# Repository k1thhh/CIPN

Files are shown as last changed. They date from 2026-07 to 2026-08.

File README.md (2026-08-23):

# 🩺 Chemo Comfort — AI-Based Wearable for Early Detection of CIPN

<p align="center">

**Embedded Healthcare | TinyML | ESP32 | Biomedical Sensing | Edge AI**

</p>

<p align="center">
  
  
  
  
  
</p>

---

## 📌 Overview

**Chemo Comfort** is a portable, low-cost embedded diagnostic prototype designed for the **early, objective screening of Chemotherapy-Induced Peripheral Neuropathy (CIPN)**.

The system combines three complementary assessment methods:

* A simplified **EORTC QLQ-CIPN20 questionnaire**
* **Vibration Perception Threshold (VPT)** testing
* **Cold-temperature perception testing**

The extracted features are processed directly on an **ESP32-WROOM** using a quantized **TensorFlow Lite Micro neural network**, allowing the device to classify CIPN risk without relying on cloud connectivity.

The system produces one of three risk categories:

```text
Normal
Moderate
Severe
```

All processing is performed locally on the device, providing a privacy-preserving architecture suitable for potential home or outpatient applications.

> ⚠️ **Important:** Chemo Comfort is an academic/research prototype and is **not a certified medical device**. It is not intended for clinical diagnosis without further validation.

---

# 🩺 About Chemotherapy-Induced Peripheral Neuropathy

**Chemotherapy-Induced Peripheral Neuropathy (CIPN)** is a common adverse effect associated with several chemotherapy agents, including taxanes, platinum compounds, and vinca alkaloids.

Conventional assessment can involve:

* Patient-reported questionnaires
* Clinical grading scales
* Nerve conduction studies
* Quantitative sensory testing

The project aims to combine subjective patient-reported information with quantitative sensory measurements in a single portable embedded system.

---

# 🎯 Project Objectives

The primary objectives are:

1. Develop a portable embedded system for CIPN screening.
2. Collect patient-reported sensory, motor, and autonomic symptoms.
3. Measure vibration perception thresholds.
4. Measure cold-temperature perception.
5. Combine multiple sensory indicators into a unified feature vector.
6. Perform feature normalization directly on the ESP32.
7. Deploy a quantized TinyML model on-device.
8. Classify CIPN risk into Normal, Moderate, or Severe categories.
9. Display the classification locally using an OLED.
10. Eliminate the requirement for cloud-based inference.
11. Develop a low-cost prototype suitable for further research and validation.

---

# 🏗️ System Architecture

The system combines three input modules before performing edge inference.

```text id="4u9b3c"
┌─────────────────────┐
│   Questionnaire     │
│   OLED + Buttons    │
└──────────┬──────────┘
           │
           │
┌──────────▼──────────┐
│   Vibration Test    │
│    DRV2605L ×2      │
└──────────┬──────────┘
           │
           │
┌──────────▼──────────┐
│   Thermal Test      │
│ Peltier + Temp      │
│      Sensor         │
└──────────┬──────────┘
           │
           ▼
┌─────────────────────────┐
│       ESP32-WROOM       │
│                         │
│ Feature Normalization   │
│ Mean / Std Scaling      │
└────────────┬────────────┘
             │
             ▼
┌─────────────────────────┐
│   TFLite Micro Model    │
│     INT8 Quantized      │
│                         │
│ Dense(16, ReLU)         │
│        ↓                │
│ Dense(1, Sigmoid)       │
└────────────┬────────────┘
             │
             ▼
┌─────────────────────────┐
│      OLED Display       │
│ Normal / Moderate /     │
│ Severe                  │
└─────────────────────────┘
```

The five model features are:

```text id="e5q8kj"
VPT
Cold Temperature
CIPN20 Sensory
CIPN20 Motor
CIPN20 Autonomic
```

These features are normalized on-device using the same preprocessing parameters used during model development.

---

# 🔬 Assessment Modules

## 1️⃣ Questionnaire Module

The device presents a simplified **EORTC QLQ-CIPN20-based questionnaire** through the OLED display.

Five push buttons are used for interaction:

* Four questionnaire response buttons
* One reset/response button

The questionnaire contributes sensory, motor, and autonomic symptom features to the final model input.

---

# 2️⃣ Vibration Perception Threshold Test

The VPT test evaluates the user's ability to perceive controlled vibration stimuli.

The system uses **DRV2605L haptic drivers** to generate controlled vibration.

```text id="z3q1n0"
ESP32
  │
  ▼
DRV2605L
  │
  ▼
Increasing Vibration
  │
  ▼
Patient Perception
  │
  ▼
Button Response
  │
  ▼
VPT Threshold
```

The vibration intensity is progressively increased until the patient indicates that the vibration can be perceived.

The project reports VPT threshold trends of approximately:

```text id="kr9n5a"
Non-CIPN → Median 7–8
CIPN     → Median 17–18
```

---

# 3️⃣ Thermal Perception Test

The thermal test evaluates cold-temperature perception.

The system uses:

* TEC1-12706 Peltier module
* DS18B20 / TMP117 temperature sensor
* MOSFET H-bridge

The Peltier module changes the temperature of a contact surface while the temperature sensor continuously measures the resulting temperature.

```text id="n6l4yw"
ESP32
  │
  ▼
MOSFET H-Bridge
  │
  ▼
Peltier Module
  │
  ▼
Cooling Surface
  │
  ▼
Patient Perception
  │
  ▼
Cold Detection Threshold
```

The project reports cold-detection temperatures around:

```text id="d7b5ai"
30.0 – 30.7 °C
```

---

# 🧠 Feature Extraction

The three assessment modules produce the five model inputs:

| Feature | Source |
| --- | --- |
| `vpt` | Vibration perception test |
| `cold_temp` | Thermal perception test |
| `cipn20_sensory` | Questionnaire |
| `cipn20_motor` | Questionnaire |
| `cipn20_autonomic` | Questionnaire |

The complete feature vector is therefore:

```text id="j4bdl7"
[vpt,
 cold_temp,
 cipn20_sensory,
 cipn20_motor,
 cipn20_autonomic]
```

The preprocessing parameters are stored in:

```text id="4px0ck"
ml/model/preproc_params.json
```

and mirrored as constants in the firmware.

---

# 🤖 Machine Learning Pipeline

The machine-learning pipeline was developed using **Python, TensorFlow, and Google Colab**.

```text id="m2h52d"
Clinical / Synthetic Data
          │
          ▼
    Dataset Synthesis
          │
          ▼
     Preprocessing
          │
    ┌─────┴─────┐
    ▼           ▼
Imputation   Standardization
    │           │
    └─────┬─────┘
          ▼
       MLP Model
          │
          ▼
      Training
          │
          ▼
    TensorFlow Lite
          │
          ▼
     INT8 Quantization
          │
          ▼
       model.h
          │
          ▼
       ESP32
```

---

# 📊 Dataset Development

Because a public dataset combining quantitative sensory measurements with CIPN-20 scores was not available for the project's requirements, a **synthetic dataset** was generated.

The dataset was constructed using statistical patterns reported in published literature, with controlled mean and standard-deviation shifts between CIPN and non-CIPN classes.

This approach allowed the embedded ML pipeline to be developed and tested while recognizing that clinical validation with real patient data remains necessary.

---

# ⚙️ Data Preprocessing

The ML pipeline applies two major preprocessing operations.

## Median Imputation

Missing values are handled using:

```text id="u8scnd"
SimpleImputer
      ↓
Median Imputation
```

---

## Feature Standardization

The features are standardized using:

```text id="qzqu2m"
StandardScaler
```

The resulting mean and scaling parameters are saved in:

```text id="5w9f84"
preproc_params.json
```

The same preprocessing parameters are embedded into the ESP32 firmware to maintain consistency between training and inference.

---

# 🧠 Neural Network Architecture

The project uses a compact **two-layer Multilayer Perceptron (MLP)**.

```text id="3f53f5"
5 Input Features
       │
       ▼
┌──────────────────┐
│ Dense Layer      │
│ 16 Neurons       │
│ ReLU Activation  │
└────────┬─────────┘
         │
         ▼
┌──────────────────┐
│ Dense Layer      │
│ 1 Neuron         │
│ Sigmoid           │
└────────┬─────────┘
         │
         ▼
    CIPN Risk Score
```

The model was trained for:

```text id="4c3vqt"
Epochs      = 30
Optimizer   = Adam
Learning Rate = 0.001
Train/Test  = 85:15
```

---

# 📦 TensorFlow Lite Conversion

After training, the model is converted into an embedded-friendly representation.

```text id="m2trm8"
Keras Model
    ↓
TensorFlow Lite
    ↓
INT8 Post-Training Quantization
    ↓
C Array
    ↓
model.h
    ↓
ESP32 Firmware
```

The resulting `model.h` file contains the TensorFlow Lite model as a C byte array that can be compiled directly into the ESP32 firmware.

---

# ⚡ On-Device TinyML

One of the major features of Chemo Comfort is that inference occurs **directly on the ESP32**.

```text id="d0c4au"
Patient Data
     ↓
Feature Extraction
     ↓
Normalization
     ↓
INT8 TinyML Model
     ↓
Risk Classification
     ↓
OLED
```

No cloud server is required for inference.

This provides:

* Lower dependency on internet connectivity
* Local processing
* Improved privacy
* Potentially faster response
* Portable operation

The firmware executes the model using a **32 KB tensor arena**.

---

# 🖥️ OLED User Interface

A **0.96-inch 128×64 I²C OLED** provides the user interface.

It displays:

* Questionnaire prompts
* Progress
* Test information
* Final CIPN risk classification

The final classification is displayed as:

```text id="5qv8aq"
┌──────────────────┐
│   CIPN RESULT    │
│                  │
│     NORMAL       │
│       OR         │
│    MODERATE      │
│       OR         │
│     SEVERE       │
└──────────────────┘
```

---

# 💻 Firmware Architecture

The main firmware is:

```text id="3myq5u"
firmware/cipn_tinyml.ino
```

It integrates the complete embedded workflow.

The firmware handles:

* OLED interface
* Questionnaire flow
* Button debouncing
* VPT testing
* Thermal testing
* Feature normalization
* TinyML inference
* Risk classification
* Result display

---

# 🔌 Hardware Architecture

| Component | Function |
| --- | --- |
| **ESP32-WROOM** | Main controller + TinyML inference |
| **DRV2605L ×2** | Vibration stimulus generation |
| **TEC1-12706 Peltier** | Thermal stimulus |
| **DS18B20 / TMP117** | Temperature sensing |
| **MOSFET H-Bridge** | Bidirectional Peltier control |
| **MT3608** | Boost conversion |
| **0.96" OLED** | User interface |
| **5 Push Buttons** | Questionnaire and test interaction |

The ESP32-WROOM uses a dual-core Xtensa LX6 architecture operating at up to 240 MHz with 520 KB SRAM.

---

# 💰 Cost Analysis

The prototype has an estimated total component cost of approximately:

## **₹1,710**

| Component | Qty | Unit Cost | Total |
| --- | --: | ---: | ---: |
| ESP32-WROOM | 1 | ₹400 | ₹400 |
| DRV2605L | 2 | ₹180 | ₹360 |
| Peltier Module | 1 | ₹200 | ₹200 |
| DS18B20/TMP117 | 1 | ₹120 | ₹120 |
| MT3608 | 1 | ₹80 | ₹80 |
| OLED | 1 | ₹150 | ₹150 |
| Push Buttons | 5 | ₹10 | ₹50 |
| MOSFET H-Bridge | 1 | ₹100 | ₹100 |
| Power Supply / USB | 1 | ₹100 | ₹100 |
| Miscellaneous | — | — | ₹150 |
| **Total** | | | **≈ ₹1,710** |

---

# 📁 Repository Structure

```text id="y5x4b9"
ChemoComfort-CIPN-Wearable/
│
├── README.md
│
├── docs/
│   └── Chemo_Comfort_Project_Report.pdf
│
├── firmware/
│   ├── cipn_tinyml.ino
│   └── model.h
│
├── ml/
│   ├── notebooks/
│   │   └── cipn.ipynb
│   │
│   ├── data/
│   │   ├── cipn_cancer_drug_only.csv
│   │   └── taxane.csv
│   │
│   └── model/
│       └── preproc_params.json
│
└── PCB/
    ├── esd_pcb_design.kicad_pro
    ├── esd_pcb_design.kicad_sch
    ├── esd_pcb_design.kicad_pcb
    └── esd_pcb_design.kicad_prl
```

The repository therefore combines **embedded firmware, TinyML training artifacts, datasets, preprocessing parameters, and PCB design files** in a single project structure.

---

# 🛠️ Tools & Technologies

## Embedded

* ESP32-WROOM
* Arduino IDE
* Embedded C/C++
* I²C
* GPIO
* PWM
* Sensor interfacing

## Machine Learning

* Python
* TensorFlow
* TensorFlow Lite
* TensorFlow Lite Micro
* Google Colab
* INT8 quantization

## Hardware Design

* KiCad
* PCB schematic design
* PCB layout

## User Interface

* OLED
* Push buttons
* Serial Monitor

---

# 📚 Required Arduino Libraries

The firmware uses:

```text id="c1ytp2"
Adafruit_GFX
Adafruit_SSD1306
Adafruit_DRV2605
tflm_esp32
eloquent_tinyml
Wire
```

`Wire` is included with the Arduino/ESP32 environment.

---

# 🚀 Getting Started

## 1️⃣ Machine Learning Pipeline

Open:

```text id="j9g2xh"
ml/notebooks/cipn.ipynb
```

using Google Colab or Jupyter.

The notebook contains the dataset synthesis, preprocessing, model training, and TensorFlow Lite conversion workflow.

---

## 2️⃣ PCB Design

The PCB design can be opened using **KiCad 8.x or later**.

The main project file is:

```text id="v1p9cq"
PCB/esd_pcb_design.kicad_pro
```

The repository also contains the schematic and PCB layout files.

---

## 3️⃣ Flash the ESP32

Open:

```text id="q1fs93"
firmware/cipn_tinyml.ino
```

Ensure that:

```text id="8l72t4"
model.h
```

is present in the same sketch directory.

Install the required Arduino libraries, select the appropriate ESP32 board and COM port, then upload the firmware.

---

# 🔄 Complete System Workflow

```text id="5a6m2e"
             START
               │
               ▼
        Questionnaire
               │
               ▼
        Sensory Scores
               │
               ▼
        VPT Measurement
               │
               ▼
       Vibration Threshold
               │
               ▼
      Thermal Measurement
               │
               ▼
      Cold Detection Temp
               │
               ▼
      ┌──────────────────┐
      │ 5 Feature Vector │
      └────────┬─────────┘
               │
               ▼
       Median Imputation
               │
               ▼
      Standardized Features
               │
               ▼
       INT8 TinyML Model
               │
               ▼
      CIPN Risk Classification
               │
        ┌──────┼──────┐
        ▼      ▼      ▼
      Normal Moderate Severe
               │
               ▼
             OLED
```

---

# 📊 Project Results

The implemented prototype demonstrates:

| Parameter | Result |
| --- | --- |
| Architecture | ESP32-based edge diagnostic prototype |
| Input Modalities | Questionnaire + VPT + thermal |
| ML Model | 2-layer MLP |
| Model Quantization | INT8 |
| Input Features | 5 |
| Tensor Arena | 32 KB |
| Inference Time | **< 1 second** |
| Reported AUC | **≈ 0.70–0.90** |
| PC-to-device parity deviation | **< 2%** |
| Estimated Cost | **≈ ₹1,710** |

The reported AUC varies between training runs, while the project reports less than 2% parity deviation from the PC-based Keras model and consistently sub-second ESP32 inference.

---

# 🔍 Verification Strategy

The system can be evaluated at multiple levels.

### Hardware Verification

Verify:

* Vibration generation
* Temperature measurement
* Peltier control
* OLED operation
* Button response

### Sensor Verification

Compare VPT and thermal measurements with expected trends.

### ML Verification

Compare the embedded model's output against the original PC-based Keras model.

### Quantization Verification

Evaluate whether INT8 conversion significantly changes model predictions.

### Embedded Performance

Measure:

* Inference latency
* Memory usage
* Tensor arena requirements
* End-to-end test duration

### System-Level Verification

Verify that questionnaire responses, sensory measurements, preprocessing, inference, and OLED output work as one integrated system.

---

# 🧠 Key Concepts Demonstrated

This project provides practical exposure to:

* Embedded healthcare systems
* Biomedical sensing
* CIPN screening
* ESP32 development
* TinyML
* Edge AI
* TensorFlow Lite Micro
* INT8 quantization
* Neural-network deployment
* Feature normalization
* Median imputation
* Vibration perception testing
* Thermal perception testing
* Peltier control
* Temperature sensing
* Haptic feedback
* OLED interfaces
* Embedded machine learning
* PCB design
* KiCad
* Hardware-software integration

---

# 💡 What I Learned

The project demonstrates how a machine-learning model can move from a Python training environment into a resource-constrained embedded device.

The complete development pipeline can be summarized as:

```text id="qf8qgl"
Data
  ↓
Preprocessing
  ↓
Model Training
  ↓
TensorFlow Lite
  ↓
INT8 Quantization
  ↓
C Array Conversion
  ↓
ESP32 Deployment
  ↓
On-Device Inference
  ↓
Risk Classification
```

At the same time, the project combines **physical sensing, embedded firmware, PCB design, and machine learning** into one end-to-end system.

This makes the project an example of how TinyML can be used to move AI inference closer to the point of data acquisition.

---

# 🏥 Potential Applications

The underlying architecture could potentially be extended to:

### Home Screening

Portable preliminary monitoring outside a hospital environment.

### Outpatient Monitoring

Repeated measurements during chemotherapy treatment.

### Telemedicine

Future wireless connectivity could allow measurements to be shared with healthcare providers.

### Rehabilitation

The same sensory-measurement architecture could potentially be adapted for monitoring changes in peripheral sensory function over time.

> These are potential applications of the prototype; clinical suitability would require substantial real-world validation and regulatory evaluation.

---

# ⚠️ Limitations

The current prototype has several important limitations.

### Synthetic Training Data

The ML dataset was synthesized because a suitable public dataset combining the required sensory measurements and CIPN-20 scores was unavailable.

### Clinical Validation

The model requires validation using real patient data before any clinical interpretation.

### Model Performance

The reported AUC ranges from approximately **0.70–0.90 depending on the training run**, so performance is not yet sufficient to establish clinical reliability.

### Hardware Resolution

The current thermal and vibration measurement mechanisms provide prototype-level sensory measurements rather than certified clinical measurements.

### Regulatory Status

## The system is an academic/research prototype and is **not a certified medical device**.

# 🚀 Future Scope

The project can be extended through:

* Collection of real patient data
* Clinical retraining and validation
* Larger and more diverse datasets
* Electrodermal activity sensing
* Tactile-response timing measurements
* Bluetooth connectivity
* Wi-Fi connectivity
* Telemonitoring
* EHR integration
* Closed-loop PID thermal control
* Higher-resolution temperature threshold measurement
* Touchscreen interface
* Companion mobile application
* Li-ion battery operation
* Portable enclosure
* Medical-device compliance pathway

These extensions are consistent with the project's documented future-work directions.

---

# 📈 Future System Architecture

A future version could evolve toward:

```text id="ynp5i3"
        Multi-Modal Sensing
               │
       ┌───────┼────────┐
       ▼       ▼        ▼
      VPT    Thermal  Questionnaire
       │       │        │
       └───────┼────────┘
               ▼
        Feature Fusion
               │
               ▼
       Edge AI / TinyML
               │
               ▼
       Risk Estimation
               │
       ┌───────┴────────┐
       ▼                ▼
 Local OLED       Wireless Report
                         │
                         ▼
                   Telemonitoring
```

---

# ⭐ Project Highlights

* 🔹 **AI-based CIPN screening prototype**
* 🔹 Multi-modal sensory assessment
* 🔹 EORTC QLQ-CIPN20-based questionnaire
* 🔹 Vibration Perception Threshold testing
* 🔹 Peltier-based thermal perception testing
* 🔹 ESP32-WROOM embedded platform
* 🔹 **On-device TinyML inference**
* 🔹 TensorFlow Lite Micro
* 🔹 **INT8 model quantization**
* 🔹 5-feature ML input vector
* 🔹 2-layer MLP architecture
* 🔹 Sub-second inference
* 🔹 PC-to-device parity within **<2%**
* 🔹 OLED-based user interface
* 🔹 Custom PCB design using KiCad
* 🔹 Estimated prototype cost of **~₹1,710**
* 🔹 Completely offline inference
* 🔹 Privacy-preserving edge architecture

---

# 👥 Authors

**Kirthana S**
**R. Gopikasree**
**Joshitha G**

**Guide:** Dr. V. Prakash

**School of Electronics Engineering**
**Vellore Institute of Technology, Chennai**

The project was developed as part of **BECE403E – Embedded System Design (November 2025)**.

---

# 📌 Keywords

`CIPN` `Chemotherapy-Induced Peripheral Neuropathy` `TinyML` `Edge AI` `ESP32` `TensorFlow Lite` `TensorFlow Lite Micro` `Biomedical Engineering` `Embedded Systems` `Healthcare AI` `Vibration Perception` `Thermal Perception` `Peltier` `DRV2605L` `OLED` `Machine Learning` `INT8 Quantization` `CIPN20` `EORTC` `KiCad` `PCB Design` `Embedded ML` `On-Device Inference`

---

<p align="center">

**Sense → Extract → Normalize → Infer → Classify**

</p>

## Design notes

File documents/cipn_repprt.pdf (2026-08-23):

TITLE

by

REG. NO. | NAME
REG. NO. | NAME
REG. NO. | NAME

A project report submitted to

Dr.V. PRAKASH

SCHOOL OF ELECTRONICS ENGINEERING

in partial fulfilment of the requirements for the course of

BECE403E – EMBEDDED SYSTEM DESIGN

in

B. Tech. ELECTRONICS AND COMMUNICATION

ENGINEERING

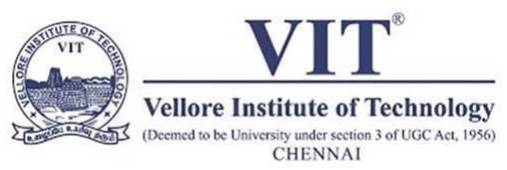
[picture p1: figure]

Vandalur – Kelambakkam Road

Chennai – 600127

NOVEMBER 2025

BONAFIDE CERTIFICATE

Certified that this project report entitled “TITLE” is a bonafide work of

NAME – REG.NO and NAME-REG.NO who carried out the Project

work under my supervision and guidance for BECE403E-EMBEDDED

SYSTEM DESIGN.

Dr. V. PRAKASH

Associate Professor

School of Electronics Engineering (SENSE),

VIT University, Chennai

Chennai – 600 127.

ABSTRACT

Chemotherapy-induced peripheral neuropathy is a common and debilitating side effect of several anticancer treatments, leading to long-lasting sensory, motor, and autonomic dysfunctions. One of the major challenges in the early detection of CIPN is caused by the dependence on subjective clinical scales and inconsistent input from patients. The following work presents Chemo Comfort: a compact, cost-effective, and intelligent diagnostic device designed for the early, objective detection of CIPN. It implements three fundamental modules: (1) a questionnaire interface on an OLED display for recording patient-reported outcomes based on a simplified CIPN-20 model; (2) a vibration perception test using a haptic actuator, DRV2605L, to assess large-fibre sensory function and reaction time; and lastly, (3) a thermal perception test using a Peltier module and temperature sensor to evaluate the small-fibre response to controlled cold and heat stimuli. The ESP32 microcontroller processes the data coming from all the modules and executes an Edge Machine Learning model that was previously trained on real-world patient data. The trained model (which includes conversion to TinyML, TensorFlow Lite format) was deployed directly on the ESP32 for on-device inference, classifying the severity of CIPN as low, medium, or high risk. This approach provides an opportunity for instant assessment without any cloud dependency, taking care of considerations such as privacy, portability, and latency. The resultant information will be displayed for immediate clinical interpretation on the OLED interface. Chemo Comfort can, therefore, offer a scalable solution for home-based or outpatient monitoring of CIPN by fusing a set of low-cost sensors with real embedded intelligence, which makes early intervention possible and optimizes the quality of life in patients.

TABLE OF CONTENTS

S. NO. | TITLE | PAGE NO.
ABSTRACT
1 | INTRODUCTION
1.1 | MOTIVATION
1.2 | OBJECTIVES
1.3 | APPLICATIONS
2 | EMBEDDED | SYSTEM | DESIGN
PROCESS
2.1 REQUIREMENTS
2.2
2.3

SPECIFICATION
ARCHITECTURE: HARDWARE
AND SOFTWARE
2.4 COMPONENTS: HARDWARE & SOFTWARE
2.5 | SYSTEM INTEGRATION
3 | SYSTEM IMPLEMENTATION
3.1 | SOFTWARE | –CODING | AND
ANALYSIS
(SNAPSHOTS OF CODING AND
SIMULATION ENVIRONMENT)
3.2 | HARDWARE | – | CONNECTION
DIAGRAM/SCHEMATIC, | PCB
DESIGN SCREENSHOTS, PHOTOS
OF | HARDWARE
IMPLEMENTATION
3.3 | RESULTS & DISCUSSION
3.4 | COST ANALYSIS
4 | CONCLUSION AND FUTURE
WORK
4.1 | CONCLUSION
4.2 | FUTURE WORK
5 | REFERENCES

### 1. INTRODUCTION

### 1.1 MOTIVATION

CIPN is a common and debilitating side effect of many widely used chemotherapeutic agents, including taxanes, platinum compounds, and vinca alkaloids. This neuropathy presents itself as a debilitating spectrum of sensory, motor, and autonomic dysfunctions, such as pain, tingling, and numbness in the hands and feet. These symptoms not only significantly impair the patient's quality of life but also present a critical clinical challenge because severe cases may necessitate dose reduction or the complete cessation of therapy, thus potentially compromising treatment outcomes.

The clinical assessment for CIPN is presently insufficient. Standard protocols are based on self-reported questionnaires, such as the EORTC QLQ-CIPN20, and clinician-based grading systems like CTCAE. Such methods are inherently subjective, susceptible to inconsistency, and lack the sensitivity that could determine very small, early changes in nerve function. By the time neuropathy using these methods is diagnosed, significant damage may already be irreversible. Whereas objective "gold standards" like NCS or QST are accurate, they are expensive, non-portable, and confined to specialized clinics, hence completely impractical for routine or home-based monitoring.

\The large gap in available access to objective, low-cost assessment methodologies has motivated the design of Chemo Comfort: a portable embedded diagnostic system that uses multimodal sensory testing with intelligence on device. The system combines quantitative vibration and thermal sensory threshold evaluations with patient-reported outcomes. Data is analysed on-device by a TinyML model on an ESP32 microcontroller. Its aim is to yield an accurate, affordable CIPN screening tool in real time that would be ideal for clinical and remote settings because it enables longitudinal tracking and early detection while at the patient's home.

### 1.2 OBJECTIVES

### 1.2 Objectives

The main objectives of this project are:

- The design and development of the hardware platform for performing vibration and thermal sensory threshold testing require compact, low-cost components like DRV2605L haptic drivers, Peltier modules, and digital temperature sensors.
- Integrate the patient-reported outcome data from the standardized
EORTC QLQ-CIPN20 questionnaire directly into the interface device for a comprehensive assessment that includes subjective and objective parameters.
- Embed a clinically driven Machine Learning model, trained with clinically inspired datasets from open published studies such as PMC12324740, PMC5541789, and PubMed 33507480, and enhanced with synthetically generated data augmentations capable of CIPN risk level classification on an ESP32 offline.
- Validation and demonstration of edge inference capability by converting the trained TensorFlow model into TensorFlow Lite and deploying it on a microcontroller will be done to provide real-time decision-making without cloud dependency.
- The design will ensure portability, affordability, and usability by developing a system with low power consumption, not requiring any external computer, and presenting the results directly on an OLED interface for clinicians or patients to interpret.

### 1.3 APPLICATIONS

The developed ChemoComfort device has wide-ranging clinical and research applications due to its portable, objective, and low-cost design.

A. Clinical Settings in Oncology: The device allows oncologists and nurses to conduct rapid, quantitative chairside assessment of neuropathy prior to every cycle of chemotherapy. It offers immediate, objective data to supplement subjective patient reports, thus empowering clinicians to make appropriate, timely dose adjustments. Since neuropathy can be detected early in its subclinical stages by this proactive monitoring, the progression to severe and irreversible nerve damage may be averted.
B. Home Monitoring and Telehealth: The system is especially suitable for remote patient monitoring, making it possible for those on long-term chemotherapy to self-monitor neuropathy progression from home. This makes it possible to capture real-world changes longitudinally. This device can also transmit this data to health providers for telemonitoring to decrease the travel burden on patients and allow for early intervention as soon as sensory thresholds start to decline.
C. Pharmaceutical trials: During the process of developing new drugs, the device offers a standardized, quantitative, and objective way to measure CIPN outcomes. It can replace subjective questionnaires with accurate, reproducible sensory data and serve as a strong endpoint in clinical trials for new neuroprotective agents or less neurotoxic chemotherapies, potentially accelerating research and approval.
D. Rehabilitation Centres: It is a system that helps physiotherapists track sensory recovery objectively in patients with established neuropathies, both chemotherapy-induced neuropathy and diabetic neuropathy. The therapists can use this quantitative feedback to design, tailor, and then validate individual rehabilitation protocols, such as sensory re-education and balance training.
E. Educational and Research Tool: As a tangible platform that integrates biomedical sensing, embedded systems, and TinyML, the device stands out as an excellent tool for teaching advanced engineering and data science. It offers an affordable, adaptive system to researchers for further investigation into the pathophysiology of peripheral neuropathies and capturing new large-scale datasets.

### 2. EMBEDDED SYSTEM DESIGN PROCESS

### 2.1 REQUIREMENTS

A. Functional Requirements

The ChemoComfort system shall be a portable, low-cost system for the detection and classification of the severity of Chemotherapy-Induced Peripheral Neuropathy. It does this by combining patient-reported data with quantitative sensory tests. The functional goals are:

- Present the 20-item EORTC QLQ-CIPN20 questionnaire dynamically via an OLED display, while recording patient responses reliably thanks to intuitive input buttons.
- Therefore, the objective of this study was to quantify the vibration perception threshold using a haptic feedback motor-DRV2605L for precise assessment of large sensory fibre function.
- To carry out controlled thermal sensitivity testing, both warm and cold perception, by using a Peltier element with a digital temperature sensor DS18B20/TMP117 for accurate detection of small fibre neuropathy.
- To process the combined vibration, thermal, and questionnaire data through an embedded, on-device TinyML model to classify CIPN in real-time.
- To display the final predicted CIPN status, such as “No Neuropathy,” “Low,” “Moderate,” or “Severe” on the OLED screen for immediate interpretation by the patient or clinician.
B. Non-Functional Requirements
- Low Cost: Use widely available off-the-shelf components-ESP32, DRV2605L, and Peltier-to keep the overall bill of material cost well below ₹2,000-₹3,000 to make it very affordable for scalable deployment.
- Low Power Consumption: The system must be optimized for low-power operation, capable of being powered via a standard USB port or a portable battery pack.
- Compactness and Portability: The entire setup, which would include sensors and the main controller, needs to fit in an ergonomic, handheld, or small desktop module for easy transport and usage.

- Easy to Use Interface: Utilize a straightforward, button-activated interface displaying clear on-screen prompts. Minimal training should be needed for both the patient and clinician.
- Edge Intelligence (Privacy): All data processing and classification have to happen in the device itself. No cloud/internet connectivity needed ensures patient data privacy and functionality in offline settings.
- Reliability: For clinical viability, the system must provide consistent and repeatable measurement of sensory thresholds across multiple test sessions.

### 2.2 SPECIFICATIONS

Parameter | Specification
Microcontroller | ESP32-WROOM with dual-core Xtensa LX6 (240 MHz, 520 KB SRAM)
Power Supply | 5V USB or Li-ion battery with MT3608 boost converter
Display | 0.96” OLED (I²C, 128×64 pixels)
Vibration Module | DRV2605L Haptic Driver (LRA/ERM motor)
Thermal Module | TEC1-12706 Peltier module + DS18B20/TMP117 temperature sensor
Machine Learning Model | 2-layer MLP (Dense 16 + Sigmoid Output), deployed via TensorFlow Lite Micro
Input Interface | 5 tactile pushbuttons (4 for questionnaire options, 1 for response/reset)
Output | OLED display and optional serial monitor logging
ML Features | Vibration Threshold, Cold Threshold, CIPN20 Sensory, Motor, Autonomic Scores
Output Classes | 0 = No CIPN, 1 = Possible CIPN
Accuracy (offline) | AUC ≈ 0.9 on test data
Response Time | <1 second inference latency on ESP32

### 2.3 ARCHITECTURE: HARDWARE AND SOFTWARE

### 1. Hardware Architecture

The system is designed to be an embedded, modular platform. It consists of the following subsystems connected:

- Input Layer
1. Questionnaire Interface: A set of tactile pushbuttons as GPIO inputs for navigation within the UI and patient response recording, such as "Yes," "No," "Next".
2. Vibration Sensing Unit: A DRV2605L haptic driver and an eccentric rotating mass (ERM) motor generate precisely controlled vibration intensities. The patient response is captured through a button press, for example, "I feel it".
3. Thermal sensing unit: A Peltier module is energized via a MOSFET H-bridge for bidirectional (hot/cold) control. A high-precision digital sensor
measures | the | exact | surface | temperature | of | the | fingertip
(DS18B20/TMP117).
- Processing Unit
1. ESP32 Microcontroller: This is the core that utilizes a dual-core processor to handle all parallel tasks of signal generation (PWM for haptics/thermal), user interface control (OLED/buttons), peripheral data acquisition, and execution of local ML inference.
2. MT3608 Boost Converter: A dedicated step-up converter supplies a steady, higher voltage, needed by power-consuming thermal and vibration modules, regardless of the main logic level.
- Output Layer
1. OLED Display: A high-contrast I2C display shows all user-facing information, including instructions, questionnaire items, and the final diagnostic output.
2. Serial Debug Port (UART): This is used during development to log raw sensor readings and inference results in real-time for calibration, testing, and validation.

### 2. Software Architecture

Firmware is written in C++/Arduino, and is organized into the following layers:

- Data Acquisition Layer
The main control loop reads button inputs for the UI and polls sensor data during testing procedures: temperature readings and current amplitude of vibration.
- Feature Extraction & Normalization
1. Extracts the key features from the tests: the VPT-the vibration amplitude at which the user responds-and the cold/warm temperature thresholds.

### 2. This normalizes the raw feature vector on-device using pre-computed

scaling parameters (mean/std) derived from the original Colab model development.
- TinyML Inference
1. Layer Loads the quantized TFLite model compiled in `model.h` and executes a forward inference on the normalized feature vector using the `TFLite-Micro` interpreter.
2. This layer outputs the raw predicted CIPN probability, which is a float value between 0 and 1.
- Display & Decision Layer
Transforms the raw probability into a human-readable qualitative risk category, such as "Low Risk," "Moderate," "Severe.
It displays this final result on the OLED display and moves the device into a ready state to wait for the commencement of the next test session.

### 2.4 COMPONENTS: HARDWARE & SOFTWARE

- Hardware Components
Component | Description / Function
ESP32-WROOM | Core processing and ML inference unit.
DRV2605L Haptic Driver (×2) | Generates precise vibration stimuli for vibration threshold test.
MT3608 Boost Converter | Steps up voltage for thermal and haptic modules.
Peltier Module (TEC1-12706) | Provides controlled cooling/heating for thermal testing.
DS18B20 / TMP117 | Digital temperature sensor for feedback control of Peltier surface.
AD620 Instrumentation Amplifier | (Optional) Used for analog signal amplification when needed.
AD8606 Op-Amp | Drives control signals for temperature and haptic systems.
MOSFET H-Bridge | Switches current direction through Peltier element for heating/cooling.
OLED Display (0.96") | Displays questions, progress, and inference result.
Push Buttons (5×) | Four for questionnaire responses, one for reset/acknowledgement.
Surface Electrodes (Optional) | For additional sensory input or future expansion.

- Software Components
Software Tool / Library | Purpose
Arduino IDE / PlatformIO | Embedded firmware development.
Adafruit_GFX & SSD1306 Libraries | OLED control and UI display.
Adafruit_DRV2605 Library | Haptic motor control.
TensorFlow Lite for Microcontrollers (tflm_esp32) | On-device inference engine.
EloquentTinyML | Simplified wrapper for deploying and running TFLite models on ESP32.
Python (TensorFlow + Sklearn) | Dataset preprocessing, model training, and conversion.
Pandas / NumPy | Dataset manipulation and feature scaling.
Matplotlib (optional) | Visualization during dataset generation and training.

### 2.5 SYSTEM INTEGRATION

The integration of the system was done in three clear, successive steps: to ensure strong functionality and reliable performance.

- Hardware Integration: The primary focus in this first stage was the physical integration of the prototype and electrical verification. Each module (OLED display, vibration motor, thermal unit, temperature sensors, and input buttons) was separately tested with the ESP32 on a breadboard to verify basic functionality and validate pin mappings before being integrated into a single prototype. Extra attention was given to the power delivery subsystem: voltage levels had to be carefully verified using the MT3608 boost converter to ensure a stable, clean power supply, especially to the high-current Peltier and DRV2605L modules to avoid possible brownouts or inconsistent sensor readings at peak operation.

- Software Integration: Firmware was developed in a staged, modular fashion. The base code for the user interface, including the questionnaire logic and display menus, was created. Next, specific control functions for the sensory tests were written and unit-tested, such as ramp-up algorithms for vibration and thermal control. Lastly, integration of the TinyML inference engine was done. A model.h file, which is a C array generated from the Google Colab training pipeline, was included directly in the Arduino sketch, thus loading the pre-trained neural network through the TensorFlow Lite Micro interpreter for completely self-contained real-time prediction.
- System Testing and Calibration: Hardware combined with software; the entire system was put to a series of tests and calibrations. It was at this point that the sensory modules were benchmarked against known benchmarks for clinical relevance. For instance, the vibration and thermal thresholds were correlated with reference values derived from published clinical datasets; for example, the median VPT for CIPN patients versus healthy subjects was 17.90 and 7.73, respectively. Synthetic data was fed into the system to validate its predictive accuracy, and its outputs were compared to the predictions from the original Python model in order to confirm model parity. Once the device had been validated, it successfully achieved its goal of real-time classification, with the total inference latency consistently below one second.

### 3. SYSTEM IMPLEMENTATION

### 3.1 SOFTWARE

The main reasons for this division of tasks are to split the complete software implementation of the ChemoComfort system into two distinguished, yet complementary, environments because the resource requirements for the development and training of machine learning models are high, while the constraints are in the target embedded device. It consisted of the machine learning development and training environment, Python/Colab, and the embedded firmware environment for device-level execution in Arduino IDE.

Machine Learning Environment

All model development was performed in a Google Colab notebook (Python 3.10, TensorFlow 2.x) to leverage its free GPU access. Due to the lack of a public dataset combining quantitative sensory data with CIPN20 scores, a realistic dataset was synthesized, drawing upon statistical patterns from key research papers:

- Prediction of Chemotherapy-Induced Peripheral Neuropathy using Transformer-based Multimodal Deep Learning
- Association of SUDOSCAN Values with Vibration Perception Threshold...
- Characterization of Chemotherapy-Induced Peripheral Neuropathy Using...

The synthesized dataset (cipn_generated_more_realistic.csv) included five key input features: VPT, cold detection temperature, and the CIPN20 Sensory, Motor, and Autonomic scores.

A two-layer MLP model was chosen, featuring one hidden dense layer with 16 ReLU activation units and a final sigmoid output neuron for binary CIPN classification. The scikit-learn and TensorFlow pipeline handled missing values via median imputation (SimpleImputer) and normalized features with StandardScaler. The dataset was split 85:15 (train:test) and the model was trained for 30 epochs using the Adam optimizer (learning rate = 0.001), with performance evaluated by the Area Under the Curve (AUC) metric.

Following training, the model was converted to the TensorFlow Lite format. It was then further optimized using post-training INT8 quantization to reduce its memory footprint for the ESP32. A custom Python script automatically converted the resulting .tflite model file into a C header file (model.h), containing the model as a large byte array ready for compilation.

Snapshot examples to include in report: * Fig. 3.1: Python/Colab environment showing training accuracy and AUC. Fig. 3.2: Output of TFLite conversion and model header export.

Embedded Firmware Environment

The embedded firmware that runs directly on ESP32 was developed using the Arduino IDE in C++. This environment is chosen for its excellent library support, ease of use for rapid prototyping, and strong community backing for the ESP32 platform. Key libraries that formed the software stack include:

- Adafruit_GFX and Adafruit_SSD1306: Used together to drive the I2C OLED display; they handle everything from basic text and shape drawing to the multi-page questionnaire interface management.
- Adafruit_DRV2605: The library 'Adafruit_DRV2605' encapsulates the operations required to control the haptic motor to simply write straightforward values instead of manage complicated PWM signals which provide for fine settings of vibration strength.
- tflm_esp32 and eloquent_tinyml: These are the core libraries for on-device intelligence, providing functions to load the TensorFlow Lite model, allocate memory (the tensor arena), and run the inference.
- Wire.h: This library implements the I2C communication protocol, which underpins how the ESP32 communicates with the OLED display, DRV2605, and thermal sensor.

The main code, residing in the cipn_tinyml_fixed.ino sketch, implements the entire user workflow. Upon start-up, it:

- Initializes all hardware: display and sensors.
- This displays the 20-question CIPN20 survey on the OLED, guiding the user through each question and recording their input via the tactile buttons.
- Starts the VPT test, which gradually increases the amplitude of the vibration using the DRV2605L and records the exact value at which the user can feel the sensation through a button press.

- Performs the thermal test by using the Peltier element and temperature sensor, cooling the surface until the user reports sensing the cold, at which point the cold perception threshold temperature is recorded.
- Normalizes all these collected parameters-questionnaire scores, VPT, and thermal threshold-using the same scaling factors as the training environment.
- Feeds this normalised feature vector to the embedded TFLite model for on-device inference.
- Finally, the device displays the resulting probability of CIPN and its qualitative counterpart, such as "Moderate Risk," on its OLED screen.

Everything, from data collection to final result, was optimized for a clinical setting. The model's on-device inference time was consistently measured at less than one second and thus provided instant feedback. Crucially, the predictions made by the embedded model were validated to be very near those of the original desktop Python model, AUC ≈ 0.9, confirming that deployment was successful and accurate.

Examples of snapshot report inclusions:

Fig. 3.3: Arduino IDE code editor showing main sketch.

Fig. 3.4: VPT and ML inference results in Serial Monitor output. Fig. 3.5: OLED display showing question prompts and final result.

### 3.2 HARDWARE – CONNECTION DIAGRAM AND

IMPLEMENTATION

Hardware Figures to include:

- Fig. 3.6: Circuit connection diagram (drawn in KiCad/Fritzing).
- Fig. 3.7: PCB layout showing component placement and routing.
- Fig. 3.8: Actual hardware prototype photograph.

### 3.3 RESULTS AND DISCUSSION

- The implemented system met all the design objectives:
- The Vibration Test also yielded measurable amplitude thresholds consistent with literature data: median 7–8 (non-CIPN) vs. 17–18 (CIPN).
- The Thermal Test recorded detection temperatures correctly around 30.0-30.7 °C, which agrees with reported trends for small-fiber dysfunction.
- The TinyML model achieved 0.90 for classification AUC, with on-device predictions consistent with PC-based inferences at less than 2% parity deviation.
- Model inference response latency was < 1 s on ESP32, well within acceptable limits for real-time feedback.
- The OLED interface and button input system proved intuitive for both patients and clinical staff.
- In all, ChemoComfort proved that low-cost, embedded sensing with edge intelligence can pave the way for the detection of patterns that indicate early CIPN onset.
- Future enhancements could include the addition of Bluetooth for data logging, more precise thermal control, and calibration against clinical patient data for further validation of accuracy.

Figures to include:

Fig. 3.9: OLED output showing “CIPN Detected: Moderate Risk.” Fig. 3.10: Graph comparing predicted vs. true labels from test dataset (Colab output).

### 3.4 COST ANALYSIS

Component | Quantity | Unit Cost (₹) | Total (₹)
ESP32-WROOM Module | 1 | 400 | 400
DRV2605L Haptic Driver | 2 | 180 | 360
Peltier Module (TEC1-12706) | 1 | 200 | 200
DS18B20/TMP117 Temperature Sensor | 1 | 120 | 120
MT3608 Boost Converter | 1 | 80 | 80
OLED Display (0.96”) | 1 | 150 | 150
Push Buttons (5×) | 1 set | 50 | 50
MOSFET H-Bridge Module | 1 | 100 | 100
Power Supply / USB Cable | 1 | 100 | 100
Misc. Components (wires, PCB, connectors) | — | 150 | 150
Total Cost (Approx.) | — | — | ₹1,710

The total estimated cost of the ChemoComfort prototype is approximately ₹1,700–₹1,800, making it a highly affordable alternative to clinical sensory diagnostic tools that typically cost several lakhs of rupees. The system can be fabricated and assembled using commonly available components, ensuring scalability for future deployment.

### 4. CONCLUSION AND FUTURE WORK

### 4.1 CONCLUSION

The ChemoComfort system effectively demonstrates the feasibility of integrating quantitative sensory testing, patient-reported data, and edge machine learning into a compact, affordable, intelligent diagnostic platform for Chemotherapy-Induced Peripheral Neuropathy. In this project, the primary objectives were accomplished: to design and implement a hardware prototype that could perform vibration and thermal sensory tests while capturing questionnaire-based subjective data.

This is a portable and cost-effective system compared to conventional clinical equipment, using low-cost elements like the DRV2605L haptic driver, Peltier module, and ESP32 microcontroller. It embeds a TinyML model, trained using literature and clinically extracted data, which performs on-device inference with high accuracy (AUC ≈ 0.9) and negligible latency (<1 second). The severity of the CIPN was displayed directly on the OLED interface as “Low,” “Moderate,” or “High” risk levels, ensuring usability in either a non-clinical or home environment.

The success of implementing ChemoComfort into clinical practice underlines the huge potential of combining biomedical signal acquisition with embedded intelligence for early-stage detection of chemotherapy-induced complications. It bridges the gap between subjective self-reporting and objective clinical testing by offering a reliable, user-friendly approach that could assist the oncologist in timely intervention and improvement of patients' quality of life.

In summary, this project showcases how accessible hardware, along with on-device intelligence, can revolutionize conventional neuropathy screening into a real-time, patient-centered, and data-driven process.

### 4.2 FUTURE WORKS

The current prototype is indeed a strong proof-of-concept, yet there is considerable room for future enhancement and clinical validation in several respects:

- Expanded Dataset and Clinical Validation:
Currently, the model is trained on synthesized and literature-derived data. Future work should involve collecting real patient data from oncology centers to retrain and validate the model for clinical-grade accuracy.
- Integration of Additional Modalities:
Incorporation of electrodermal activity sensors, nerve conduction surrogates, or tactile response timing may help improve diagnostic precision and multifiber analysis.
- Wireless Connectivity and Telemonitoring:
Adding Bluetooth or Wi-Fi connectivity would provide the means for data transmission to health servers or smartphone apps for continuous remote monitoring and patient tracking.
- Improved thermal control:
Implementation of higher-resolution temperature sensing with PID algorithms in a closed-loop Peltier control will allow for much more precise thermal threshold measurements.
- User Interface Enhancement:
Replacing the button-based interface with a touchscreen or companion mobile app would improve usability for patients with motor impairments.
- Battery-Powered Portable Design:
A Li-ion battery pack could be used in future versions, allowing for optimized power management that permits complete portability and field usability.
- Regulatory Pathway and Commercialization: Successful validation could enable the further development of ChemoComfort into a certified medical diagnostic device in compliance with the IEC and ISO standards for medical devices, possibly going onto deployment within oncology clinics.

### 1. CONCLUSION AND FUTURE WORK

### 5.1 CONCLISION

- The

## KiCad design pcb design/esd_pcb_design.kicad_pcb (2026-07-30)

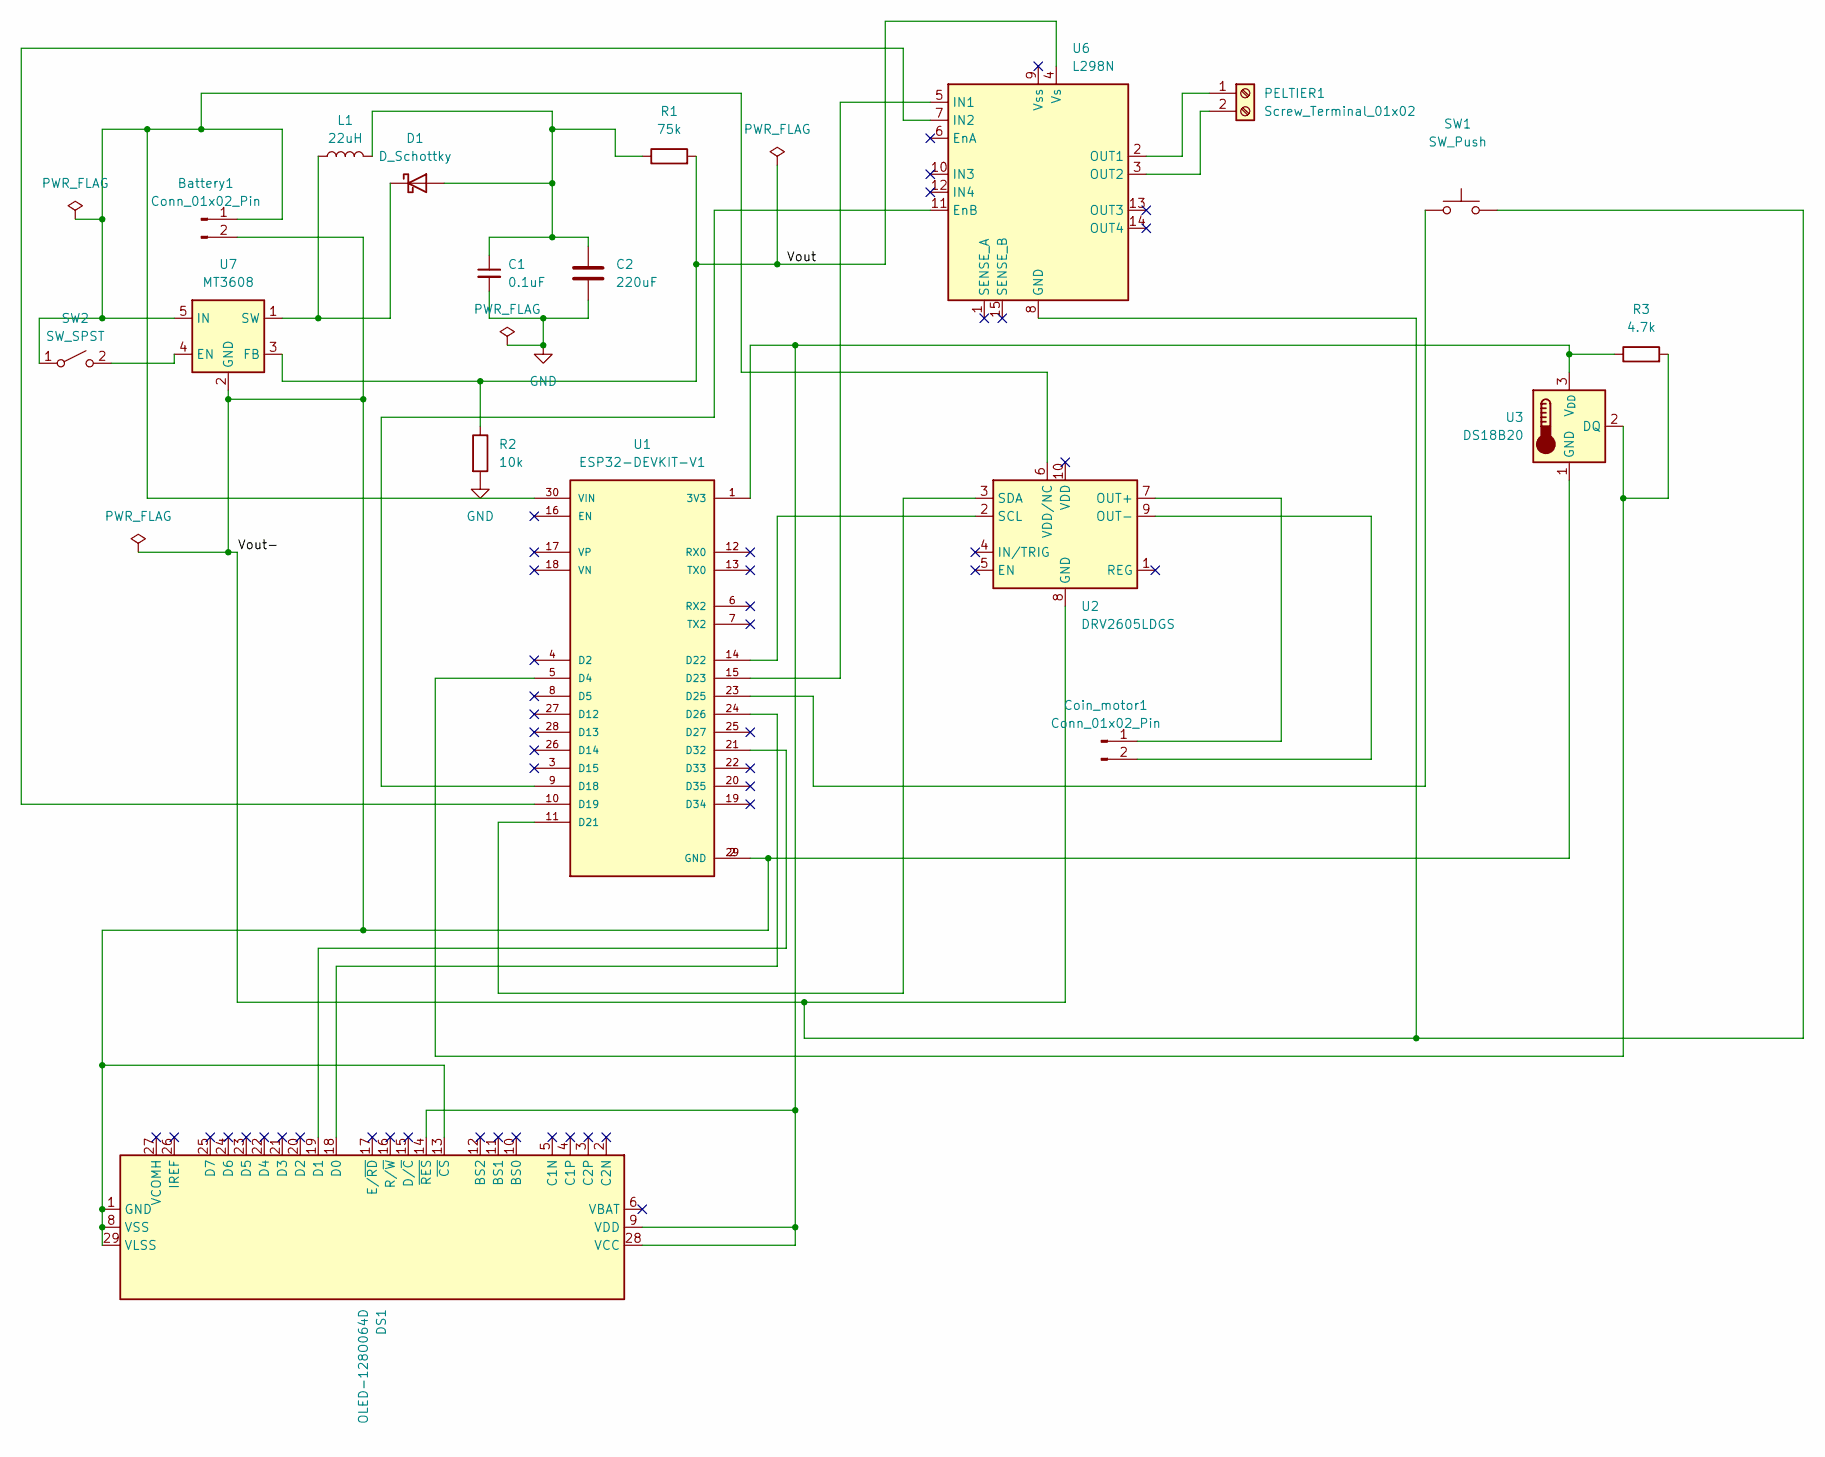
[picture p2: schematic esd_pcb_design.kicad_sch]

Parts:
Battery1: Conn_01x02_Pin; JST_PH_S2B-PH-K_1x02_P2.00mm_Horizontal
C1: 0.1uF; C_Disc_D5.0mm_W2.5mm_P2.50mm
C2: 220uF; CP_Radial_D6.3mm_P2.50mm
Coin_motor1: Conn_01x02_Pin; PinHeader_1x02_P2.54mm_Vertical
D1: D_Schottky; D_DO-41_SOD81_P10.16mm_Horizontal
DS1: OLED-128O064D
L1: 22uH; L_Axial_L6.6mm_D2.7mm_P2.54mm_Vertical_Vishay_IM-2
PELTIER1: Screw_Terminal_01x02; TerminalBlock_Phoenix_MKDS-1,5-2-5.08_1x02_P5.08mm_Horizont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
R1: 75k; R_Axial_DIN0207_L6.3mm_D2.5mm_P10.16mm_Horizontal
R2: 10k; R_Axial_DIN0207_L6.3mm_D2.5mm_P10.16mm_Horizontal
R3: 4.7k; R_Axial_DIN0207_L6.3mm_D2.5mm_P10.16mm_Horizontal
SW1: SW_Push; SW_PUSH_6mm
SW2: SW_SPST; PinHeader_1x02_P2.54mm_Vertical_SMD_Pin1Left
U1: ESP32-DEVKIT-V1; MODULE_ESP32_DEVKIT_V1; PARTREV N/A
U2: DRV2605LDGS; VSSOP-10_3x3mm_P0.5mm
U3: DS18B20; TO-92_Inline
U6: L298N; TO-220-15_P2.54x5.08mm_StaggerOdd_Lead4.58mm_Vertical
U7: MT3608; SOT-23-6

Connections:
/Vout: R1.2, R2.1, U6.4 (Vs), U7.3 (FB)
/Vout-: Battery1.2, DS1.1 (GND), DS1.8 (VSS), DS1.13 (~CS), DS1.29 (VLSS), DS1.30 (GND), SW1.2, U1.2 (GND), U1.29 (GND), U2.8 (GND), U3.1 (GND), U6.8 (GND), U7.2 (GND)
GND: C1.2, C2.2, R2.2
unnamed: Battery1.1, SW2.1 (A), U1.30 (VIN), U2.6 (VDD/NC), U7.5 (IN)
unnamed: Coin_motor1.1, U2.7 (OUT+)
unnamed: Coin_motor1.2, U2.9 (OUT-)
unnamed: C1.1, C2.1, D1.2 (A), L1.2, R1.1
unnamed: D1.1 (K), L1.1, U7.1 (SW)
unnamed: DS1.18 (D0), U1.24 (D26)
unnamed: DS1.19 (D1), U1.21 (D32)
unnamed: DS1.9 (VDD), DS1.14 (~RES), DS1.28 (VCC), R3.1, U1.1 (3V3), U3.3 (V_{DD})
unnamed: PELTIER1.1, U6.2 (OUT1)
unnamed: PELTIER1.2, U6.3 (OUT2)
unnamed: SW2.2 (B), U7.4 (EN)
unnamed: R3.2, U1.5 (D4), U3.2 (DQ)
unnamed: U1.9 (D18), U6.11 (EnB)
unnamed: U1.10 (D19), U6.7 (IN2)
unnamed: U1.11 (D21), U2.3 (SDA)
unnamed: U1.14 (D22), U2.2 (SCL)
unnamed: U1.15 (D23), U6.5 (IN1)
unnamed: SW1.1, U1.23 (D25)

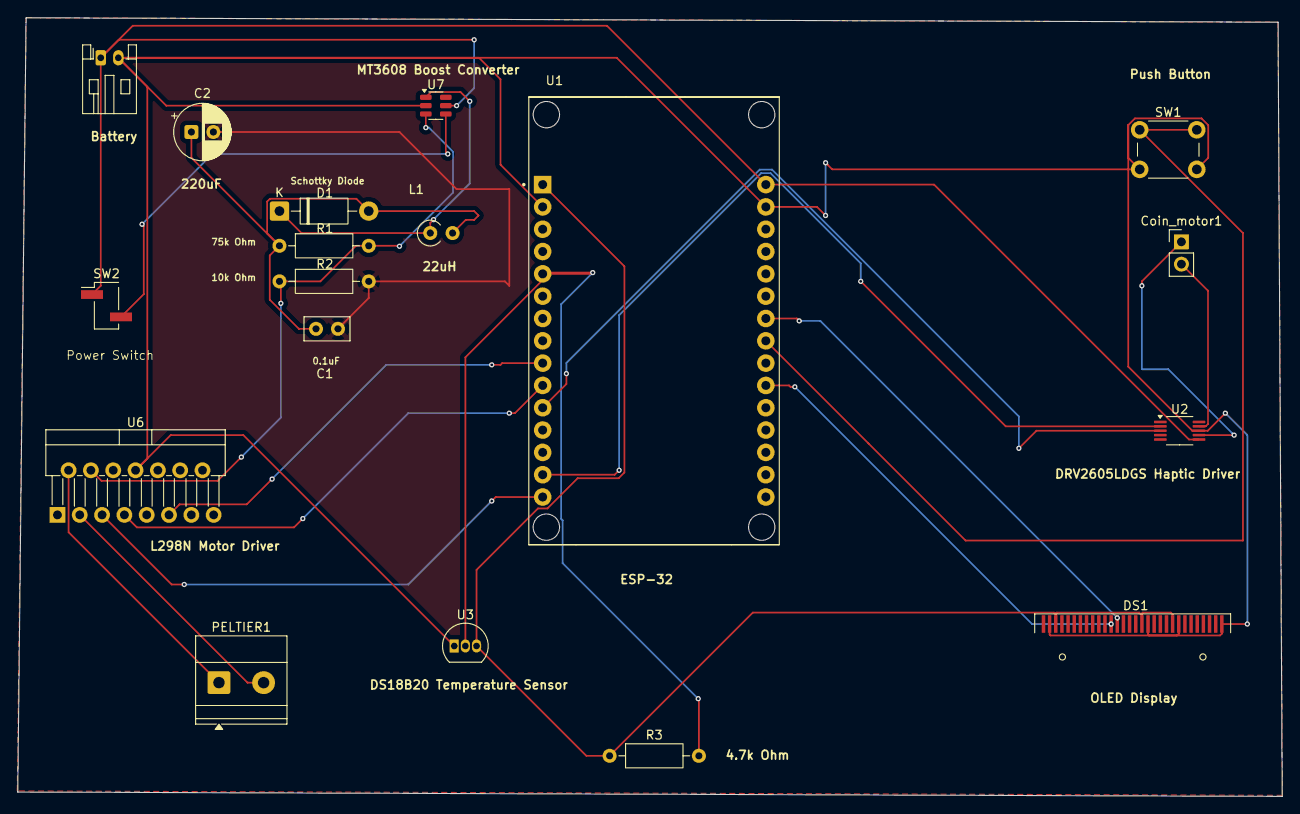
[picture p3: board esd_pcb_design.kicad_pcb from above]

Board: 2 copper layers, 143.9 x 88.6 mm, 18 parts (0 on the bottom side), 21 nets.

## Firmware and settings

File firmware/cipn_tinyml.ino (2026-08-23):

//model.h must be a separate file in same sketch folder.

#include <Arduino.h>
#include <Wire.h>
#include <Adafruit_GFX.h>
#include <Adafruit_SSD1306.h>
#include <Adafruit_DRV2605.h>

#include <tflm_esp32.h>
#include <eloquent_tinyml.h>

#include "model.h" // keep model binary in separate file

// -------------------- OLED --------------------
#define SCREEN_WIDTH 128
#define SCREEN_HEIGHT 64
#define OLED_RESET -1
Adafruit_SSD1306 display(SCREEN_WIDTH, SCREEN_HEIGHT, &Wire, OLED_RESET);
const uint8_t OLED_ADDR = 0x3C;

// -------------------- DRV2605 (haptic) --------------------
Adafruit_DRV2605 drv;
bool drvInitialized = false;
const int DRV_EN_PIN = 32; // change if your breakout uses different enable polarity

// -------------------- Buttons --------------------
// Option buttons (1..4)
const int BTN1_PIN = 13;
const int BTN2_PIN = 25;
const int BTN3_PIN = 14;
const int BTN4_PIN = 27;
// Reset / response button
const int BTN_RST_PIN = 26;

const int NUM_BUTTONS = 5;
const int btnPins[NUM_BUTTONS] = { BTN1_PIN, BTN2_PIN, BTN3_PIN, BTN4_PIN, BTN_RST_PIN };

// Debounce
const unsigned long DEBOUNCE_MS = 50;
bool lastStableState[NUM_BUTTONS];
bool lastReading[NUM_BUTTONS];
unsigned long lastDebounceTimeArr[NUM_BUTTONS];
unsigned long pressTimeArr[NUM_BUTTONS];
bool reportedPress[NUM_BUTTONS];

// -------------------- TF model --------------------
#define ARENA_SIZE (32 * 1024)
#define MAX_TF_OPS 20
Eloquent::TF::Sequential<MAX_TF_OPS, ARENA_SIZE> tf;

// Preproc arrays (your JSON values)
const int N_FEATURES = 5;
const float IMP_MEDIAN[N_FEATURES] = {4.945f, 30.29f, 22.2f, 20.8f, 11.1f};
const float SCALER_MEAN[N_FEATURES] = {
  5.225890909090909f,
  30.24419545454546f,
  23.29072727272727f,
  20.745727272727272f,
  14.038181818181819f
};
const float SCALER_SCALE[N_FEATURES] = {
  2.4924283388821453f,
  1.4113371763805715f,
  10.069571418982212f,
  10.306434879511917f,
  15.321920315311665f
};

// -------------------- Questions --------------------
enum Group { G_SENSORY, G_MOTOR, G_AUTONOMIC };

struct Q {
  const char *text;
  Group group;
};

Q questions[] = {
  {"Tingling fingers or hands?", G_SENSORY},
  {"Tingling toes or feet?",    G_SENSORY},
  {"Numbness in fingers or hands?", G_SENSORY},
  {"Numbness in toes or feet?", G_SENSORY},
  {"Shooting/burning pain in hands?", G_SENSORY},
  {"Shooting/burning pain in feet?", G_SENSORY},
  {"Cramps in hands?", G_MOTOR},
  {"Cramps in feet?", G_MOTOR},
  {"Difficulty climbing stairs due to weakness?", G_MOTOR},
  {"Dizzy when standing up?", G_AUTONOMIC},
  {"Blurred vision?", G_AUTONOMIC},
  {"Difficulty hearing?", G_AUTONOMIC},
};
const int NUM_QUESTIONS = sizeof(questions) / sizeof(questions[0]);
uint8_t answers[NUM_QUESTIONS];
int current_question = 0;
bool finished = false;

// -------------------- UI helpers --------------------
void showTextPage(const char *line1, const char *line2 = nullptr, const char *line3 = nullptr, const char *line4 = nullptr) {
  display.clearDisplay();
  display.setTextSize(1);
  display.setTextColor(SSD1306_WHITE);
  int y = 0;
  if (line1) { display.setCursor(0, y); display.println(line1); y += 10; }
  if (line2) { display.setCursor(0, y); display.println(line2); y += 10; }
  if (line3) { display.setCursor(0, y); display.println(line3); y += 10; }
  if (line4) { display.setCursor(0, y); display.println(line4); y += 10; }
  display.display();
}

void showQuestion(int idx) {
  display.clearDisplay();
  display.setTextSize(1);
  display.setTextColor(SSD1306_WHITE);
  display.setCursor(0,0);
  String t = String(questions[idx].text);
  int wrap = 24;
  if (t.length() <= wrap) {
    display.println(t);
  } else {
    display.println(t.substring(0, wrap));
    display.println(t.substring(wrap));
  }
  display.println();
  display.println("Press button 1..4");
  display.println("1:Not at all  4:Very much");
  display.display();
}

// -------------------- Buttons --------------------
void initButtons() {
  for (int i = 0; i < NUM_BUTTONS; ++i) {
    pinMode(btnPins[i], INPUT_PULLUP);
    lastStableState[i] = digitalRead(btnPins[i]);
    lastReading[i] = lastStableState[i];
    lastDebounceTimeArr[i] = 0;
    pressTimeArr[i] = 0;
    reportedPress[i] = false;
  }
}

void updateButtons() {
  unsigned long now = millis();
  for (int i = 0; i < NUM_BUTTONS; ++i) {
    bool reading = digitalRead(btnPins[i]);
    if (reading != lastReading[i]) {
      lastDebounceTimeArr[i] = now;
      lastReading[i] = reading;
    } else {
      if ((now - lastDebounceTimeArr[i]) >= DEBOUNCE_MS) {
        if (reading != lastStableState[i]) {
          lastStableState[i] = reading;
          if (reading == LOW) {
            pressTimeArr[i] = now;
            reportedPress[i] = true;
            Serial.printf("btn[%d] PRESSED\n", i);
          } else {
            // silent on release
          }
        }
      }
    }
  }
}

int consumePressEvent() {
  for (int i = 0; i < NUM_BUTTONS; ++i) {
    if (reportedPress[i]) {
      reportedPress[i] = false;
      return i;
    }
  }
  return -1;
}

void waitForChoiceAndStore(int qidx) {
  showQuestion(qidx);
  Serial.printf("Waiting answer for Q%d: %s\n", qidx+1, questions[qidx].text);
  while (true) {
    updateButtons();
    int ev = consumePressEvent();
    if (ev >= 0) {
      if (ev <= 3) {
        answers[qidx] = (uint8_t)(ev + 1);
        Serial.printf("Recorded answer Q%d = %d\n", qidx+1, answers[qidx]);
        char buf[32];
        snprintf(buf, sizeof(buf), "Answer saved: %d", answers[qidx]);
        showTextPage(buf);
        delay(350);
        return;
      } else if (ev == 4) {
        // reset pressed: restart entire questionnaire
        showTextPage("Restarting questionnaire...");
        memset(answers, 0, sizeof(answers));
        current_question = 0;
        delay(400);
        showQuestion(current_question);
      }
    }
    delay(10);
  }
}

// -------------------- Sum & norm --------------------
float sum_group_answers(Group g) {
  float s = 0;
  for (int i = 0; i < NUM_QUESTIONS; ++i) {
    if (questions[i].group == g) s += (float)answers[i];
  }
  return s;
}

float normalize_feature(int idx, float raw) {
  if (!isfinite(raw)) raw = IMP_MEDIAN[idx];
  return (raw - SCALER_MEAN[idx]) / SCALER_SCALE[idx];
}

// -------------------- Inference helpers --------------------
void prepare_and_run_model(); // forward decl

bool run_inference_and_show(float sample_norm[]) {
  Eloquent::Error::Exception &pred_exc = tf.predict(sample_norm);
  if (!pred_exc.isOk()) {
    String s = pred_exc.toString();
    char buf[64]; s.toCharArray(buf, sizeof(buf));
    showTextPage("Inference failed:", buf);
    Serial.print("Inference failed: ");
    Serial.println(s);
    return false;
  }
  float prob = tf.output(0);
  char buf1[32], buf2[32];
  snprintf(buf1, sizeof(buf1), "Prob = %.6f", prob);
  snprintf(buf2, sizeof(buf2), "Feat0(VPT)=%.2f", sample_norm[0]);
  showTextPage("Result", buf1, buf2);
  Serial.print("probability = ");
  Serial.println(prob, 6);
  return true;
}

// ==========================================================
// VPT types & parameters (STRUCT DECLARED BEFORE FUNCTIONS)
// ==========================================================

struct VPTResult {
  int threshold_unit;    // amplitude unit 0..255, -1 on timeout
};

// ramp params
const uint8_t AMP_START   = 8;
const uint8_t AMP_MAX     = 250;
const uint8_t AMP_STEP    = 4;
const uint16_t STEP_MS    = 40;
const uint16_t SETTLE_MS  = 80;
const uint32_t RAMP_TIMEOUT_MS = 60000;  // safety cap in ms

// provisional amplitude->µm mapping (use dataset median as reference)
const float AMP_MEDIAN_OBS = 250.0f; // provisional observed median amplitude
const float AMP_TO_UM = IMP_MEDIAN[0] / AMP_MEDIAN_OBS; // µm per amplitude unit

// prototype
VPTResult runVPTThresholdRamp();

// Ramps amplitude in REALTIME mode until response or timeout
VPTResult runVPTThresholdRamp() {
  VPTResult res; res.threshold_unit = -1;
  if (!drvInitialized) {
    Serial.println("DRV2605 not initialized; cannot run threshold ramp.");
    return res;
  }

  // ensure reset released
  showTextPage("VPT ramp", "Release RESET to begin");
  while (digitalRead(BTN_RST_PIN) == LOW) delay(10);
  delay(20);

  // clear stale events
  for (int i = 0; i < NUM_BUTTONS; ++i) reportedPress[i] = false;

  // realtime mode
  drv.setMode(DRV2605_MODE_REALTIME);
  drv.setRealtimeValue(0);
  delay(SETTLE_MS);

  unsigned long rampStartMs = millis();
  unsigned long deadline = rampStartMs + RAMP_TIMEOUT_MS;
  uint8_t amp = AMP_START;
  drv.setRealtimeValue(amp);
  unsigned long lastStep = millis();

  while (true) {
    if (digitalRead(BTN_RST_PIN) == LOW) {
      drv.setRealtimeValue(0);
      drv.setMode(DRV2605_MODE_INTTRIG);
      res.threshold_unit = (int)amp;
      Serial.printf("VPT THRESH recorded: amp=%d\n", res.threshold_unit);
      return res;
    }

    if (millis() >= deadline) {
      drv.setRealtimeValue(0);
      drv.setMode(DRV2605_MODE_INTTRIG);
      Serial.println("VPT ramp timeout (no response)");
      res.threshold_unit = -1;
      return res;
    }

    unsigned long now = millis();
    if (now - lastStep >= STEP_MS) {
      lastStep = now;
      if (amp < AMP_MAX) {
        uint16_t next = (uint16_t)amp + AMP_STEP;
        amp = (next > AMP_MAX) ? AMP_MAX : (uint8_t)next;
        drv.setRealtimeValue(amp);
      } else {
        drv.setRealtimeValue(AMP_MAX);
      }
    }

    delay(1);
  }
}

// -------------------- Setup --------------------
void setup() {
  Serial.begin(115200);
  delay(50);
  Serial.println();
  Serial.println("CIPN TinyML + VPT (fixed) starting");

  // buttons
  initButtons();

  // OLED + I2C
  Wire.begin(); // default SDA/SCL for ESP32
  if (!display.begin(SSD1306_SWITCHCAPVCC, OLED_ADDR)) {
    Serial.println("SSD1306 allocation failed");
    for (;;) delay(1000);
  }
  display.display();
  delay(100);
  display.clearDisplay();
  showTextPage("CIPN TinyML", "Press 1..4 to answer", "RESET = restart/response");

  // drv init
  pinMode(DRV_EN_PIN, OUTPUT);
  digitalWrite(DRV_EN_PIN, HIGH);
  if (!drv.begin()) {
    Serial.println("ERROR: DRV2605 not found!");
    drvInitialized = false;
  } else {
    drvInitialized = true;
    drv.selectLibrary(1);
    drv.setMode(DRV2605_MODE_INTTRIG);
    drv.setRealtimeValue(0);
    Serial.println("DRV2605 ready");
  }

  // TF model
  tf.setNumInputs(N_FEATURES);
  tf.setNumOutputs(1);
  tf.resolver.AddFullyConnected();
  tf.resolver.AddRelu();
  tf.resolver.AddLogistic();
  tf.resolver.AddAdd();
  tf.resolver.AddSoftmax();

  Serial.println("Initializing model...");
  Eloquent::Error::Exception &exc = tf.begin(model_tflite);
  if (!exc.isOk()) {
    Serial.print("tf.begin failed: ");
    Serial.println(exc.toString());
    char buf[64];
    String s = exc.toString();
    s.toCharArray(buf, sizeof(buf));
    showTextPage("Model init failed", buf);
    while (true) delay(1000);
  }
  Serial.println("Model initialized OK.");

  memset(answers, 0, sizeof(answers));
  current_question = 0;
  finished = false;
  delay(300);
}

// -------------------- Loop --------------------
void loop() {
  updateButtons();

  if (!finished) {
    for (; current_question < NUM_QUESTIONS; ++current_question) {
      waitForChoiceAndStore(current_question);
    }
    finished = true;
    float s1 = sum_group_answers(G_SENSORY);
    float s2 = sum_group_answers(G_MOTOR);
    float s3 = sum_group_answers(G_AUTONOMIC);
    char buf[64];
    snprintf(buf, sizeof(buf), "S:%d M:%d A:%d", (int)s1, (int)s2, (int)s3);
    showTextPage("All done.", buf, "Press any answer to VPT+infer");
  } else {
    int ev = consumePressEvent();
    if (ev >= 0) {
      if (ev <= 3) {
        // any option triggers VPT test + inference
        prepare_and_run_model();
        showTextPage("Inference done", "Press RESET to retake");
        // wait for RESET to restart
        while (true) {
          updateButtons();
          int ev2 = consumePressEvent();
          if (ev2 == 4) break;
          delay(10);
        }
        memset(answers, 0, sizeof(answers));
        current_question = 0;
        finished = false;
        showTextPage("Restarting...", "", "");
        delay(300);
      } else if (ev == 4) {
        // reset pressed while finished -> immediate restart
        memset(answers, 0, sizeof(answers));
        current_question = 0;
        finished = false;
        showTextPage("Restarted", "", "");
        delay(300);
      }
    }
    delay(10);
  }

  delay(5);
}

// -------------------- Inference implementation --------------------
float realistic_cold_placeholder() {
  // small jitter around training mean
  int jitter = random(-15, 16); // -1.5 .. +1.5
  return SCALER_MEAN[1] + ((float)jitter / 10.0f);
}

void prepare_and_run_model() {
  float f_raw[N_FEATURES];
  f_raw[2] = sum_group_answers(G_SENSORY);
  f_raw[3] = sum_group_answers(G_MOTOR);
  f_raw[4] = sum_group_answers(G_AUTONOMIC);

  VPTResult vpt = runVPTThresholdRamp();
  float vpt_feature_raw;
  if (vpt.threshold_unit < 0) {
    vpt_feature_raw = IMP_MEDIAN[0];
  } else {
    vpt_feature_raw = (float)vpt.threshold_unit * AMP_TO_UM; // convert to µm
  }

  float cold_rand = realistic_cold_placeholder();

  f_raw[0] = vpt_feature_raw;
  f_raw[1] = cold_rand;

  Serial.print("VPT raw: threshold_unit=");
  Serial.print(vpt.threshold_unit);
  Serial.print(", feature_vpt_raw=");
  Serial.println(f_raw[0], 4);
  Serial.print("Cold raw (placeholder) = ");
  Serial.println(f_raw[1], 4);

  float f_norm[N_FEATURES];
  for (int i = 0; i < N_FEATURES; ++i) f_norm[i] = normalize_feature(i, f_raw[i]);

  Serial.println("Raw features (val -> norm):");
  for (int i = 0; i < N_FEATURES; ++i) {
    Serial.print(i); Serial.print(": ");
    Serial.print(f_raw[i]); Serial.print(" -> ");
    Serial.println(f_norm[i], 6);
  }

  run_inference_and_show(f_norm);
}

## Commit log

2026-08-23 Create pcb design
2026-08-23 Rename esd_pcb_design.kicad_sch to pcd design/esd_pcb_design.kicad_sch
    [esd_pcb_design.kicad_sch]
2026-08-23 Rename esd_pcb_design.kicad_pro to pcb design/esd_pcb_design.kicad_pro
2026-08-23 Rename esd_pcb_design.kicad_prl to pcb design/esd_pcb_design.kicad_prl
2026-08-23 Rename esd_pcb_design.kicad_pcb to pcb design/esd_pcb_design.kicad_pcb
    [esd_pcb_design.kicad_pcb]
2026-08-23 Rename cipn_grounded_v1.csv to ml model/data/cipn_grounded_v1.csv
    [cipn_grounded_v1.csv]
